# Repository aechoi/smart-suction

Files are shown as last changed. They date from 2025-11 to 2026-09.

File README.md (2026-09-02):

# smart-suction

Single source of truth for the smart suction cup project — a suction cup end
effector that senses contact and alignment from capacitance changes across
eight electrodes.

```
smart-suction/
├── hardware/   KiCad sources for the sense boards and interconnect PCBs
├── firmware/   ESP32 end-effector firmware
├── software/   live capture, analysis, models
└── docs/       diagrams and notes
```

Each part has its own README with setup and usage.

## How the pieces fit

```mermaid
graph LR
    S[AD7746 CDC + 8 electrodes] -->|I2C| E[ESP32 + Ethernet PHY]
    E -->|UDP over PoE| H[Host PC: capcup.udp_receiver]
    H --> A[Analysis notebooks / models]
```

The end effector (`firmware/`) samples eight capacitance channels and streams
40-byte UDP packets to a host PC. `software/` records them and runs the
analysis and position-estimation models.

## How to record data

You will need:

- 1x PoE injector
- 2x ethernet cables
- 1x computer with `software/` installed

```mermaid
graph LR
    A[Outlet] -->|Power| B[PoE Injector]
    B <-->|LAN — ethernet| C[Host PC]
    B <-->|LAN + DC — ethernet| D[End Effector]
```

Then, from `software/`, run `python -m capcup.udp_receiver -f my_capture`.
Two windows open: a rolling time-domain plot and a radial plot.

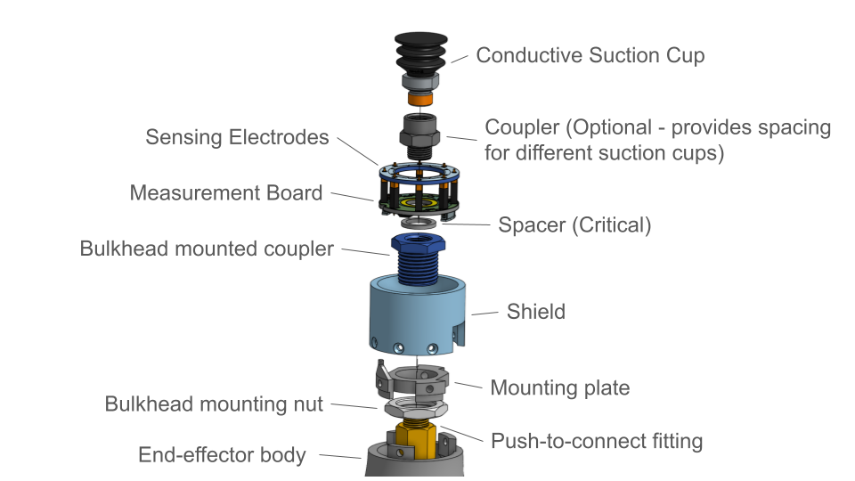
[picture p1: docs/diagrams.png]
Hardware setup


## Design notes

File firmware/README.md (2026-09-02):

# End-effector firmware

Firmware for the smart suction cup end effector. Reads eight capacitance
channels from an AD7746 CDC (multiplexed through GPIO switches) and streams
them over UDP/Ethernet to a host PC running `software/` `udp_receiver.py`.

## Target

- **MCU:** ESP32 with a LAN8720 Ethernet PHY (e.g. WT32-ETH01 / Olimex
  ESP32-POE). RMII pins are set in `ethernet.ino`
  (`MDC=23`, `MDIO=18`, `CLK=GPIO0`, `POWER=-1`).
- **Sensor:** AD7746 capacitance-to-digital converter on I2C
  (`SDA=32`, `SCL=33`, `RDY=36`, address `0x48`), with 8 channels selected
  one at a time via the switch pins in `sensing.ino`.

## Toolchain

Arduino IDE (or `arduino-cli`) with the **esp32 by Espressif** board package.
No external libraries — `ETH.h`, `WiFiUDP.h`, and `Wire.h` all ship with the
core.

The three files form one sketch (`firmware.ino` holds `setup()` / `loop()`;
`ethernet.ino` and `sensing.ino` are additional tabs). Arduino requires the
main file to match the folder name, hence `firmware.ino` in `firmware/`.

## Network configuration

Edit before flashing:

| Where | Constant | Meaning |
|---|---|---|
| `firmware.ino` | `destIP`, `destPort` | host PC address + UDP port (default `12345`) |
| `ethernet.ino` | `localIP`, `gateway`, `subnet` | static IP of the end effector |

## Wire format

One 40-byte UDP packet per sample loop:

| Bytes | Type | Contents |
|---|---|---|
| 0–7 | `uint64` LE | `millis()` timestamp |
| 8–39  | 8 × `int32` LE | raw AD7746 counts, channels 0–7 |

Convert counts to femtofarads with `count2ff()` in `sensing.ino`
(`(counts - 208400) * (4.096 * 1000 * 2) / 2^24`).

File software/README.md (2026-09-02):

# capcup — smart suction cup software

Recording and analyzing capacitance data from the smart suction cup end
effector. See the [repository README](../README.md) for the full project
(hardware, firmware, software).

## Layout

```
software/
├── src/capcup/          installable package
│   ├── udp_receiver.py   live capture + plotting from the end effector
│   ├── simulator/        capacitance-probe forward simulation
│   └── jubilee/          ground-truth collection on the Jubilee platform
├── notebooks/           analysis notebooks (outputs stripped on commit)
│   └── experiments/      one notebook per historical experiment
├── models/             trained weights (gitignored; regenerate from notebooks)
├── figs/               generated figures (gitignored)
└── tests/
```

## Setup

Run from this `software/` directory.

```bash
python -m venv .venv
.venv\Scripts\activate          # Windows
# source .venv/bin/activate     # Linux / macOS
python -m pip install --upgrade pip
pip install -e ".[dev,notebooks]"
```

`pip install -e .` alone installs just the runtime package. The Jubilee
scripts additionally need `jubilee_controller` (see `pyproject.toml`).

## Recording data

See [the repo README](../README.md#how-to-record-data) for the wiring. Then:

```bash
python -m capcup.udp_receiver -f my_capture.csv
```

Two windows open: a rolling time-domain plot and a radial plot. Captures
are written under `data/` (gitignored).

## Before pushing

```bash
pytest
ruff check .
```

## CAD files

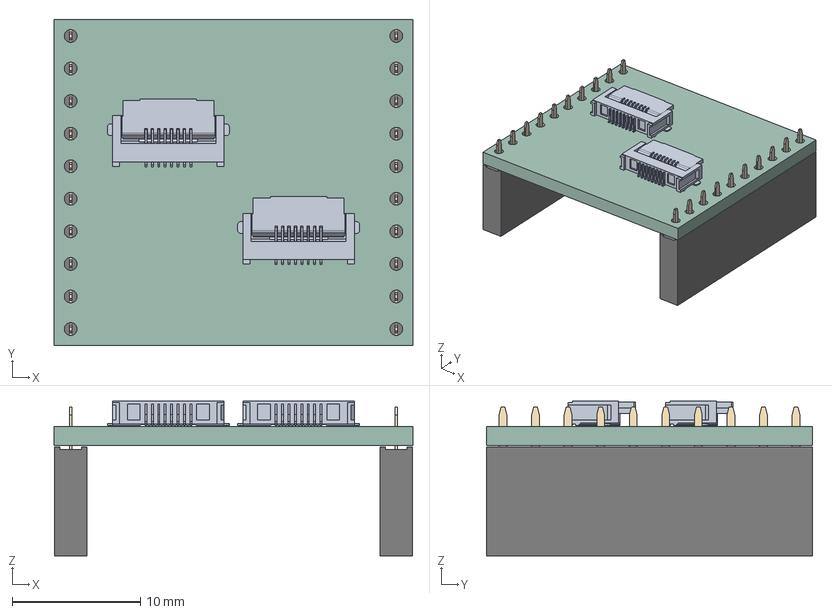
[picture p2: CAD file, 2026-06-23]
hardware/esp_pin_to_ribbon/esp_pin_to_ribbon.step
28.0 x 25.4 x 12.1 mm
PinSocket_1x10_P2.54mm_Vertical x 2
esp_pin_to_ribbon_PCB

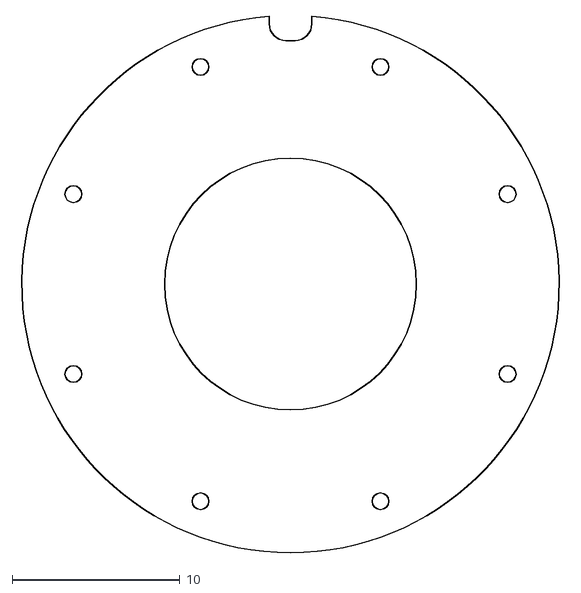
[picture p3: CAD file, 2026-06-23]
hardware/measure_board_v3/measure board 32mm.dxf
32.7 x 31.9

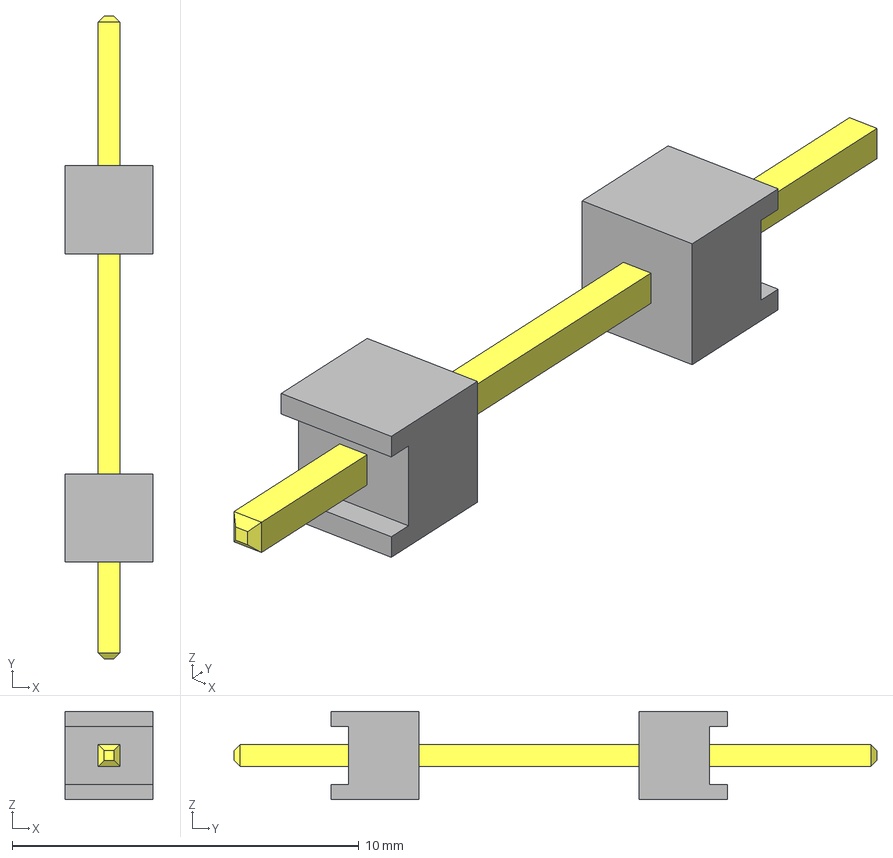
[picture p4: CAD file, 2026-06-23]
hardware/sense_board_20mm_v2/SAMTEC_DW0109TS450/DW-01-09-T-S-450.stp
2.54 x 18.5 x 2.54 mm
ZW-01-09-G-S-450-110bbody
ZW-01-09-G-S-450-110_pins
ZW-01-09-G-S-450-110_top_body

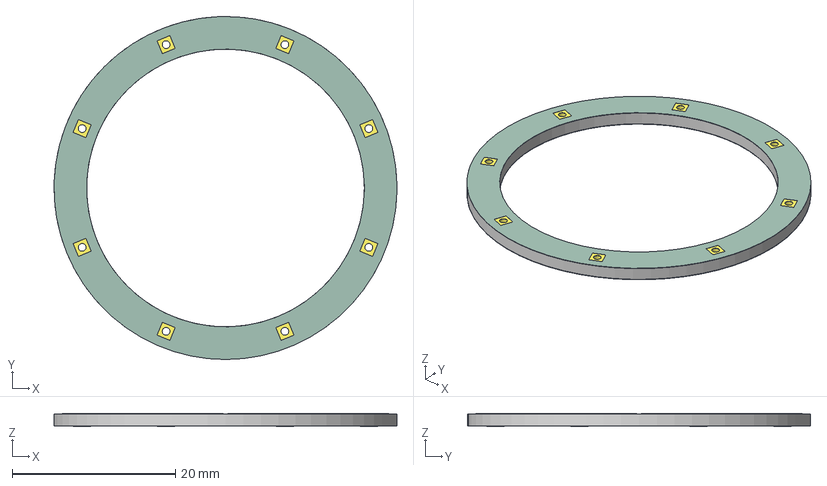
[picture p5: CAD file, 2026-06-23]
hardware/sense_board_20mm_v2/sense_board_20mm_v2.step
42.0 x 42.0 x 1.61 mm
mounted_cap_sense_v1_copper
mounted_cap_sense_v1_pad
mounted_cap_sense_v1_soldermask
mounted_cap_sense_v1_PCB

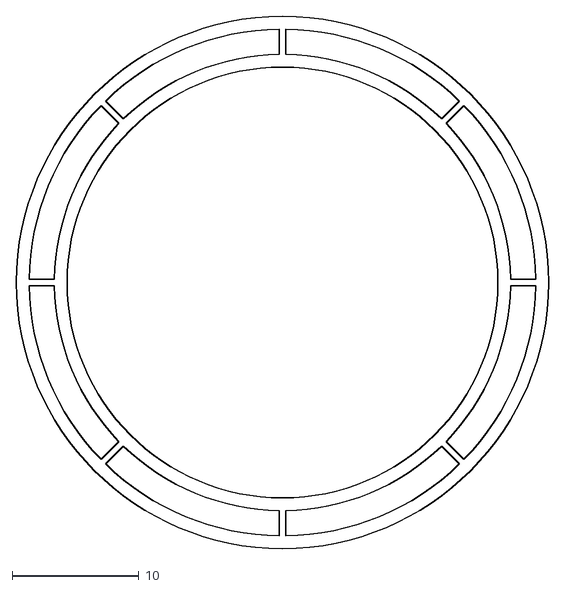
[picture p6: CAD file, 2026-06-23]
hardware/sense_board_25mm_v2/electrode_plate_v1.dxf
42.0 x 42.0

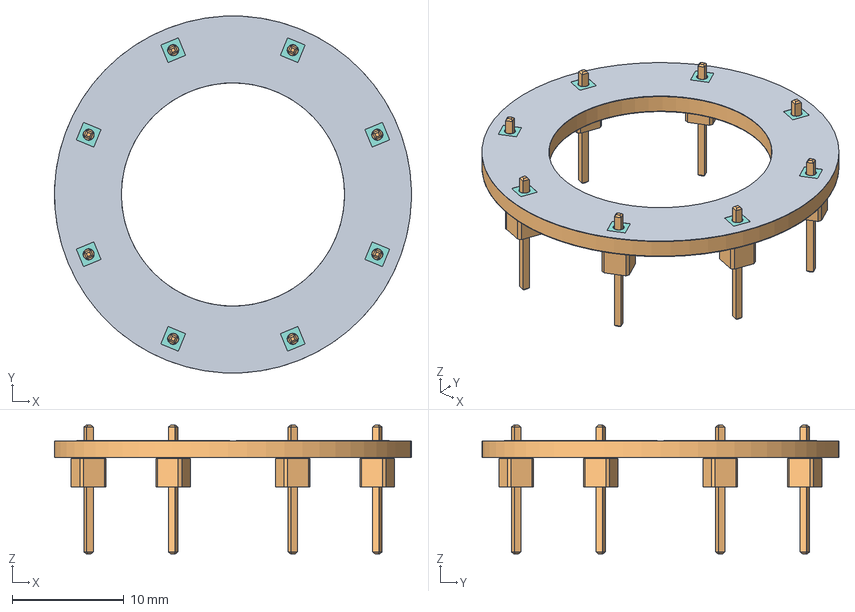
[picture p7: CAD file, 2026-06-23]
hardware/sense_board_30mm_v2/sense_board_30mm_v2.step
32.0 x 32.0 x 11.5 mm
PinHeader_1x01_P2.54mm_Vertical x 8
mounted_cap_sense_v2_25mm_copper
mounted_cap_sense_v2_25mm_pad
mounted_cap_sense_v2_25mm_soldermask
mounted_cap_sense_v2_25mm_PCB

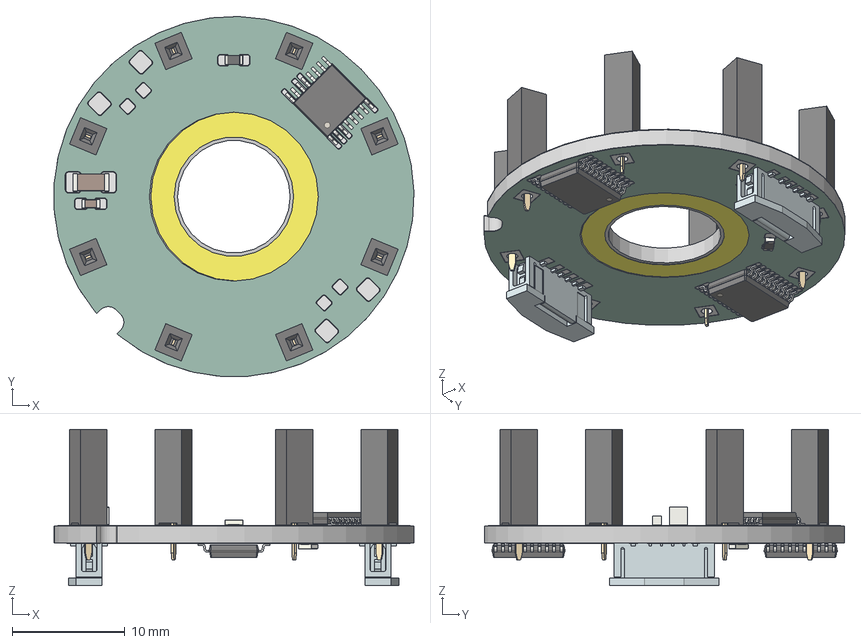
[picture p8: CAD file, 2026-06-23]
hardware/measure_board_v3/measure_board_v3.step
32.0 x 32.0 x 13.9 mm
R_0603_1608Metric x 2
PinSocket_1x01_P2.54mm_Vertical x 8
TSSOP-16_4.4x5mm_P0.65mm
C_1206_3216Metric
C_0603_1608Metric
0525590870_8pin x 2
TSSOP-20_4.4x6.5mm_P0.65mm x 2
muxed_sense_v3_copper
muxed_sense_v3_pad
muxed_sense_v3_soldermask x 2
muxed_sense_v3_PCB

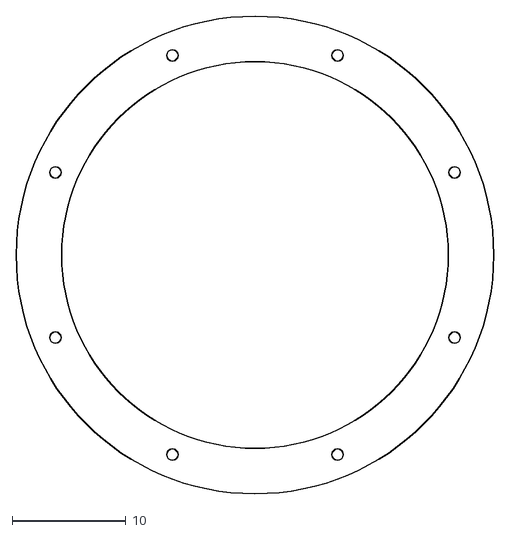
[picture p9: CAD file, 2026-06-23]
hardware/sense_board_30mm_v2/electrode_plate_holes_v1.dxf
42.0 x 42.0

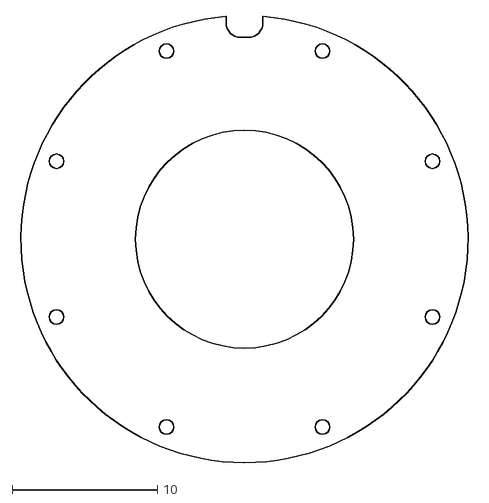
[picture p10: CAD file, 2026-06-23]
hardware/measure_board_v3/measure board 30.762mm.dxf
31.4 x 30.7

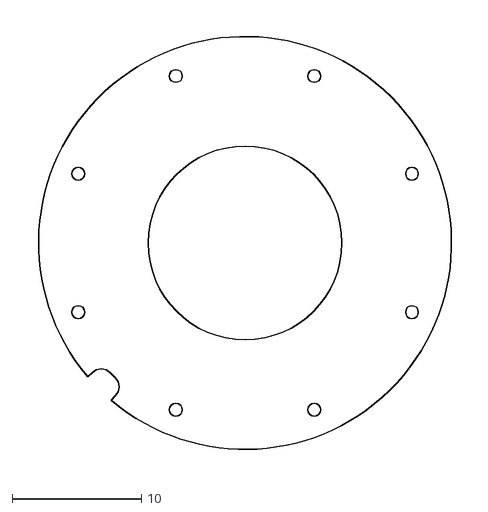
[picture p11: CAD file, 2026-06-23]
hardware/measure_board_v3/measure board 32mm flipped.dxf
35.3 x 35.3

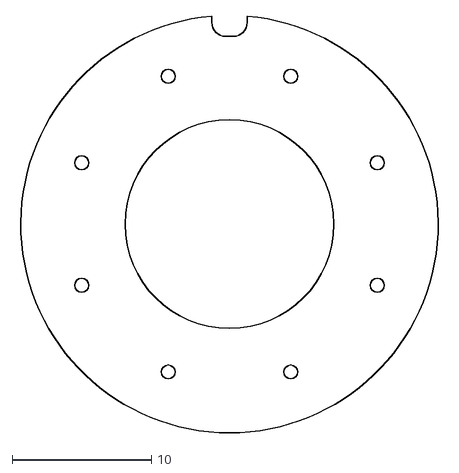
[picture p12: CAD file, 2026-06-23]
hardware/measure_board_v3/measure board 30mm.dxf
30.7 x 29.9

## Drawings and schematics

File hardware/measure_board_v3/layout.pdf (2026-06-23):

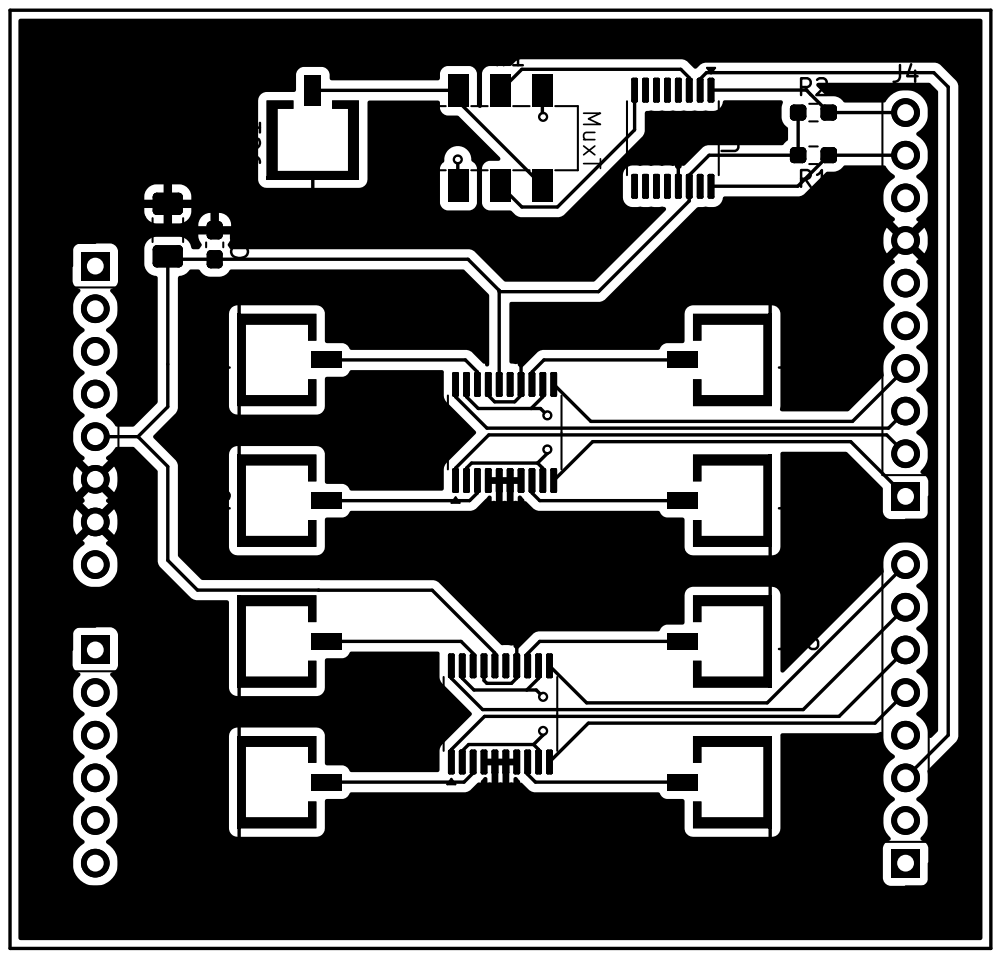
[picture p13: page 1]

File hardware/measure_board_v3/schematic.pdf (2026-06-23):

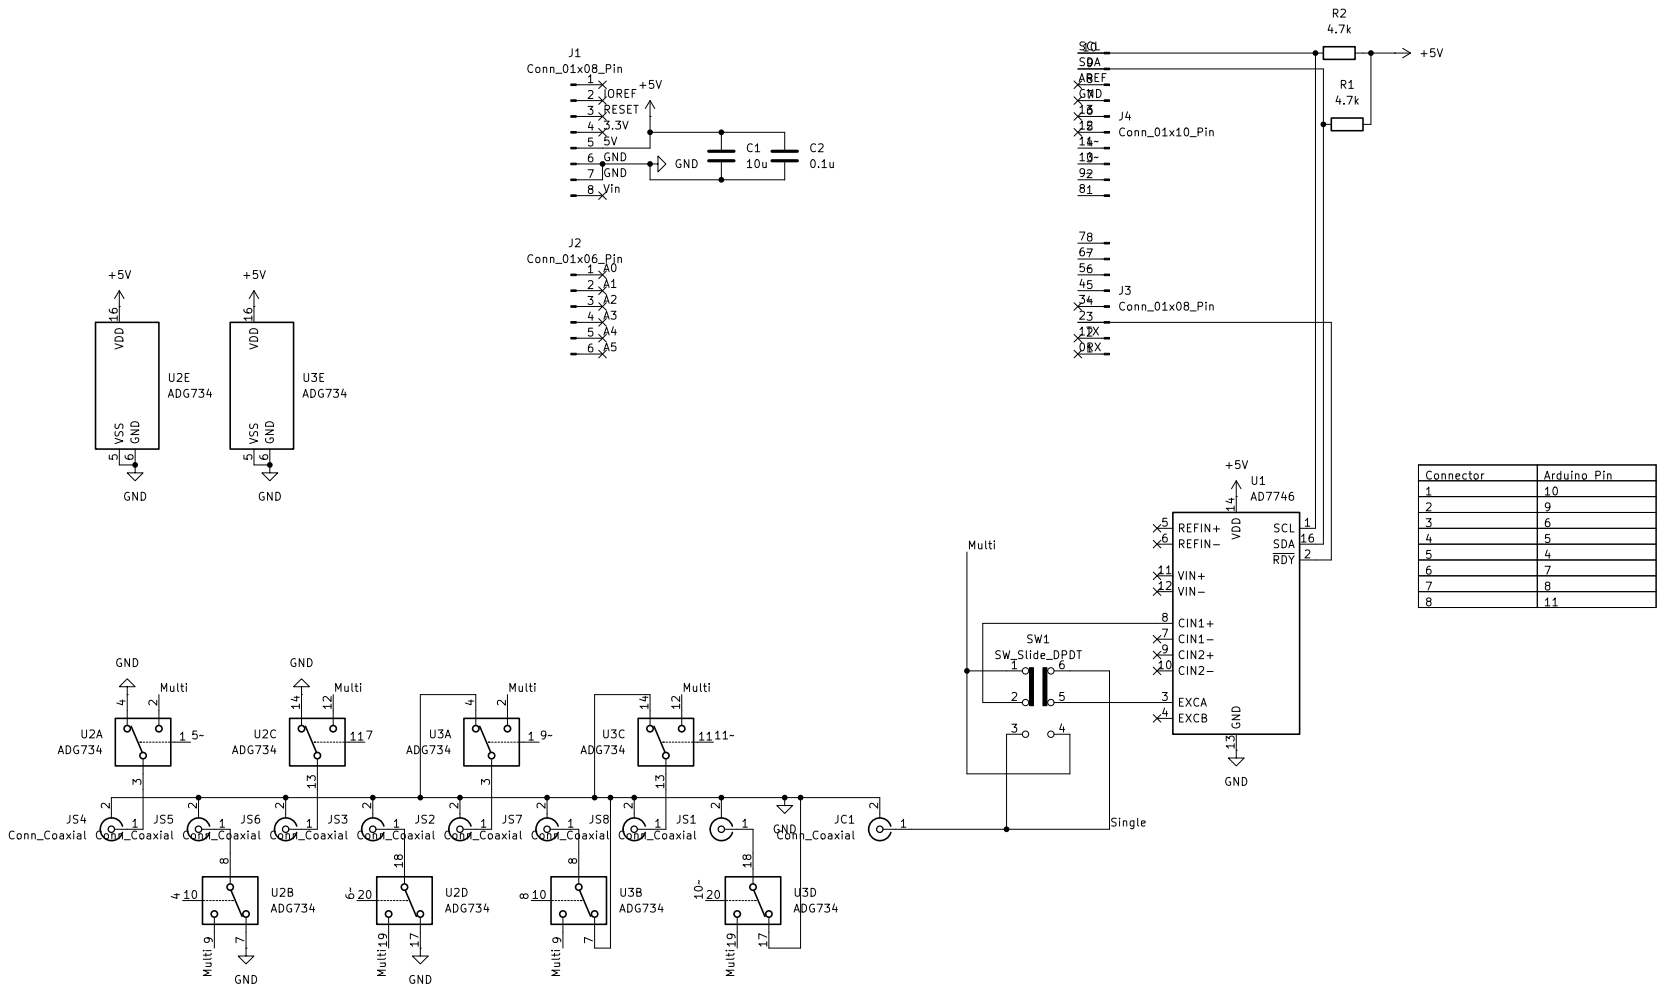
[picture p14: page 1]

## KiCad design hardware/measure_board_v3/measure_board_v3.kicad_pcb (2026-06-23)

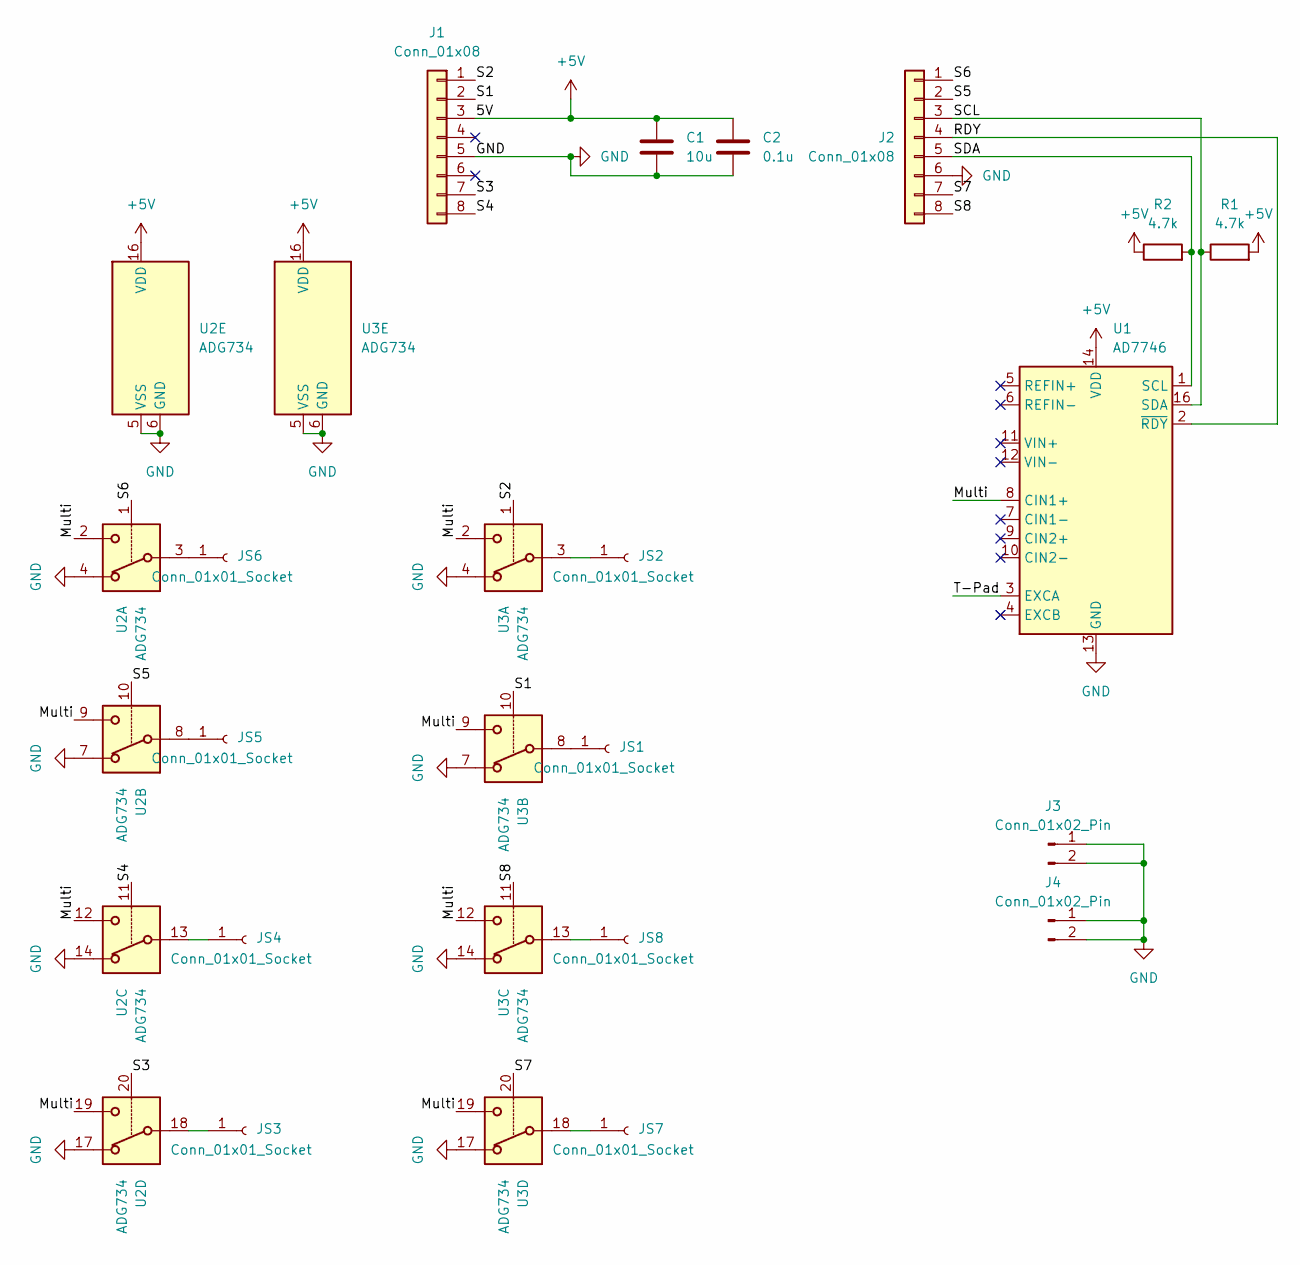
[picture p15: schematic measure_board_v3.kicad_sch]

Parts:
C1: 10u; C_1206_3216Metric_Pad1.33x1.80mm_HandSolder
C2: 0.1u; C_0603_1608Metric_Pad1.08x0.95mm_HandSolder
J1, J2: Conn_01x08; CON_525590870_MOL_8pv
J3, J4: Conn_01x02_Pin; CON_spring_00-9155-00X-85X-00X_KYOCERA
JS1, JS2, JS3, JS4, JS5, JS6, JS7, JS8: Conn_01x01_Socket; PinSocket_1x01_P2.54mm_Vertical
R1, R2: 4.7k; R_0603_1608Metric_Pad0.98x0.95mm_HandSolder
U1: AD7746; TSSOP-16_4.4x5mm_P0.65mm
U2, U3: ADG734; TSSOP-20_4.4x6.5mm_P0.65mm

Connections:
+5V: C1.1, C2.1, J1.3, R1.2, R2.1, U1.14 (VDD), U2.16 (VDD), U3.16 (VDD)
/Multi: U1.8 (CIN1+), U2.2, U2.9, U2.12, U2.19, U3.2, U3.9, U3.12, U3.19
/RDY: J2.4, U1.2 (~RDY)
/S1: J1.2, U3.10
/S2: J1.1, U3.1
/S3: J1.7, U2.20
/S4: J1.8, U2.11
/S5: J2.2, U2.10
/S6: J2.1, U2.1
/S7: J2.7, U3.20
/S8: J2.8, U3.11
/SCL: J2.3, R1.1, U1.16 (SDA)
/SDA: J2.5, R2.2, U1.1 (SCL)
/T-Pad: U1.3 (EXCA)
GND: C1.2, C2.2, J1.5, J2.6, J3.1, J3.2, J4.1, J4.2, U1.13 (GND), U2.4, U2.5 (VSS), U2.6 (GND), U2.7, U2.14, U2.17, U3.4, U3.5 (VSS), U3.6 (GND), U3.7, U3.14, U3.17
unnamed: JS1.1, U3.8
unnamed: JS2.1, U3.3
unnamed: JS3.1, U2.18
unnamed: JS4.1, U2.13
unnamed: JS5.1, U2.8
unnamed: JS6.1, U2.3
unnamed: JS7.1, U3.18
unnamed: JS8.1, U3.13

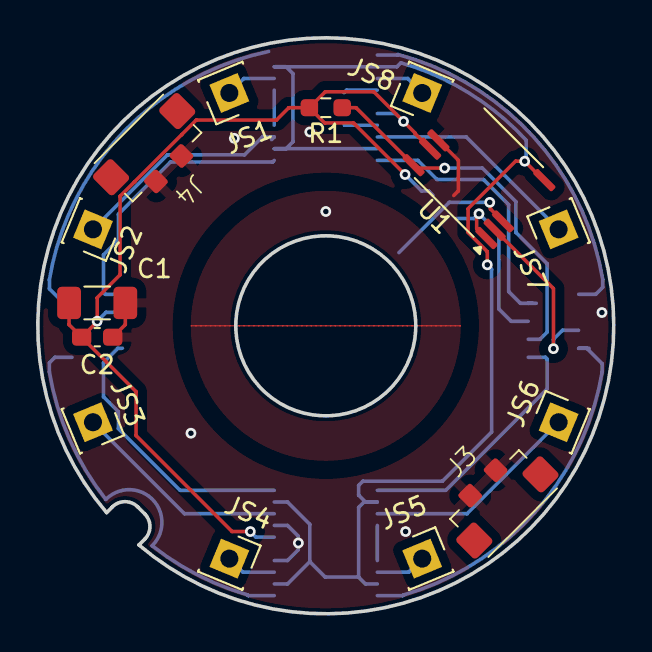
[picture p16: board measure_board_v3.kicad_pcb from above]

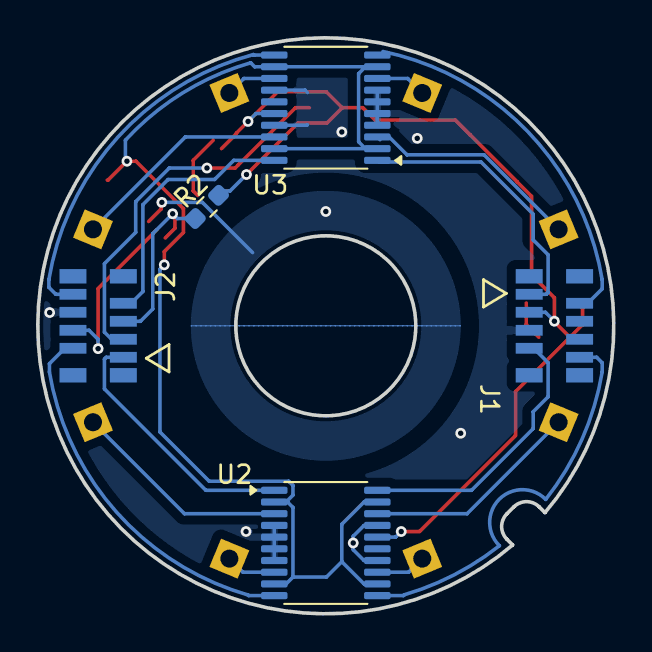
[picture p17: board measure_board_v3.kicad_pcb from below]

Board: 2 copper layers, 32.0 x 32.0 mm, 19 parts (5 on the bottom side), 22 nets.

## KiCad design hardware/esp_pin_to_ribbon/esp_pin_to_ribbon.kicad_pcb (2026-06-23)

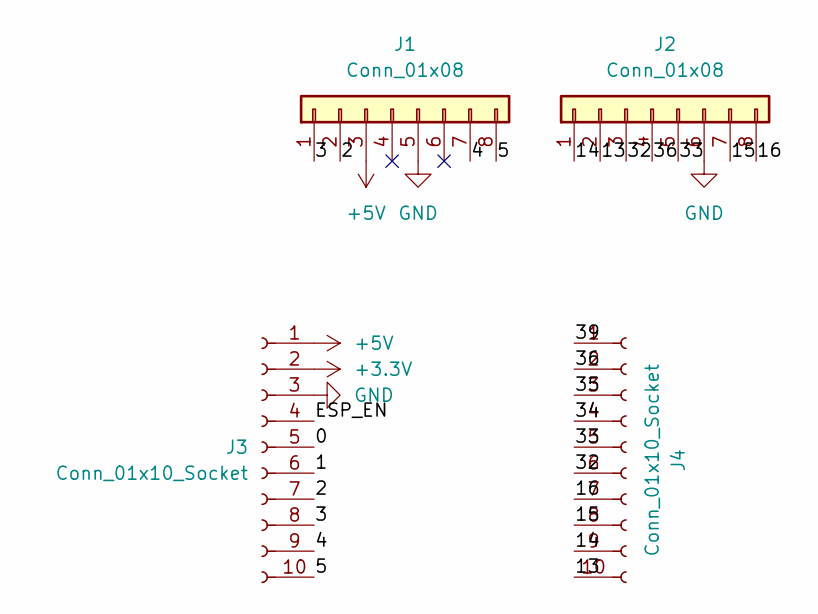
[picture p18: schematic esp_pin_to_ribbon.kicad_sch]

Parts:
J1, J2: Conn_01x08; CON_5051100892_MOL_8ph
J3, J4: Conn_01x10_Socket; PinSocket_1x10_P2.54mm_Vertical

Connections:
+3.3V: J3.2
+5V: J1.3, J3.1
/0: J3.5
/1: J3.6
/2: J1.2, J3.7
/3: J1.1, J3.8
/4: J1.7, J3.9
/5: J1.8, J3.10
/13: J2.2, J4.10
/14: J2.1, J4.9
/15: J2.7, J4.8
/16: J2.8, J4.7
/32: J2.3, J4.6
/33: J2.5, J4.5
/34: J4.4
/35: J4.3
/36: J2.4, J4.2
/39: J4.1
/ESP_EN: J3.4
GND: J1.5, J2.6, J3.3

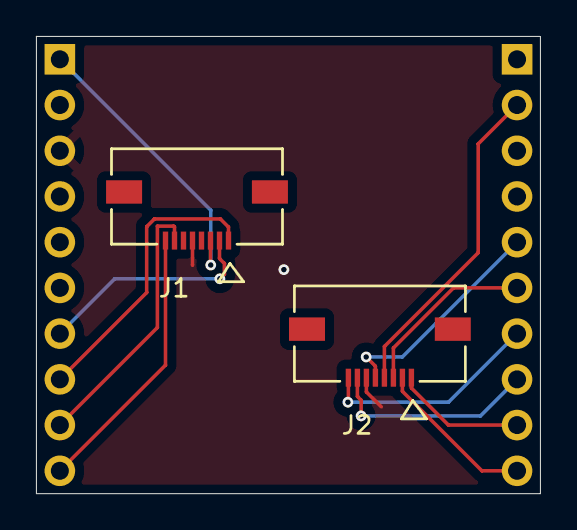
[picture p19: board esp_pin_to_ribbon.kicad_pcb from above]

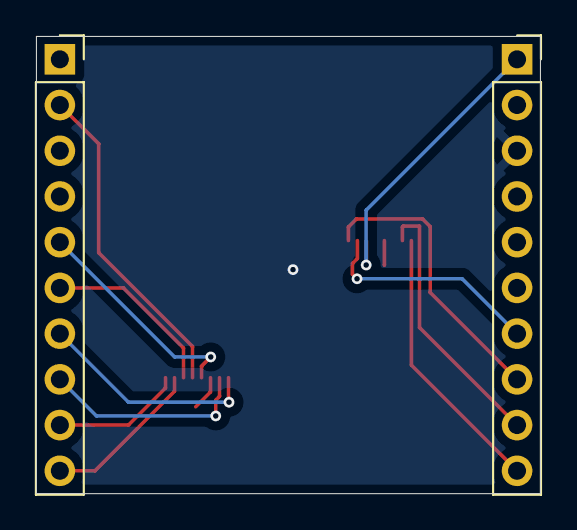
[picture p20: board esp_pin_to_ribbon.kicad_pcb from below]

Board: 2 copper layers, 28.0 x 25.4 mm, 4 parts (2 on the bottom side), 13 nets.

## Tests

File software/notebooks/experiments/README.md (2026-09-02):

# Experiment records

One notebook per experiment run, kept as a frozen record — **rendered output
is committed on purpose** (these are excluded from the `nbstripout`
pre-commit hook).

## Adding a new experiment

For anything you want to refer back to later, make a folder:

```
experiments/2026-09-15_electrode-spacing/
├── README.md      what was tested, hardware/rig config, raw-data location
├── analysis.ipynb the notebook
└── report.html    executed notebook, exported  (the permanent record)
```

Export the rendered report with:

```bash
python -m nbconvert --to html --output report.html analysis.ipynb
```

Reusable analysis code (loading a capture, SNR, standard plots) belongs in
`capcup`, not copied between notebooks. Raw captures stay out of git — note
their location in the experiment README.

## Existing notebooks

The loose `*.ipynb` here predate this convention; they are kept as-is.

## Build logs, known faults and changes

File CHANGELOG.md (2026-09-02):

# Changelog

## Repo cleanup — 2026-09-02

Reorganized from an ad-hoc layout into a hardware/firmware/software monorepo.

### Structure
- `software/` now holds the Python side (package, notebooks, tests); was the
  repo root.
- `firmware/` added — the ESP32 end-effector Arduino sketch.
- `hardware/` unchanged; `assets/` → `docs/`.
- Package `capcup`: `jubliee_scripting/` renamed to `jubilee/`, notebooks and
  `figs/` moved out of the importable package.

### Removed
- 95 KiCad auto-backup zips, stale gerber/vendor zips, `fp-info-cache`,
  `*.kicad_prl`, autosaves — all recoverable from history.
- Trained weights (`*.pt`) and generated `figs/` are no longer tracked.
- Serial capture and eval-board data-processing code — see tag
  `archive/serial-and-eval-pipeline`.

### Tooling
- `pyproject.toml`: correct package path, real dependencies, `[dev]` /
  `[notebooks]` extras, ruff + pytest config, `capcup-record` entry point.
- Added `.pre-commit-config.yaml` (ruff, nbstripout, hygiene) and a
  GitHub Actions CI workflow.
- `.gitattributes` for line-ending normalization.
- Notebook outputs stripped from the active notebooks; experiment records
  under `software/notebooks/experiments/` keep theirs.

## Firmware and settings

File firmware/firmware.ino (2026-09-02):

#include <WiFiUdp.h>

WiFiUDP udp;
// IPAddress destIP(192,168,1,100);  // your laptop
IPAddress destIP(192,168,10,102);
const uint16_t destPort = 12345;
uint8_t packet[40];
long cap_vals[8] = {0};

void setup() {
  delay(500);
  Serial.begin(115200);

  Serial.println("");
  Serial.println("Attempting Ethernet Setup...");
  ethernet_init();

  Serial.println("Attempting Sensing Setup...");
  sensing_setup();
}

void loop() {
  take_measurements(cap_vals);
  uint64_t t = millis();
  memcpy(packet, &t, sizeof(t));
  // Serial.print(t);
  // Serial.print(" ");
  // Serial.print(sizeof(t));
  // Serial.print(" ");

  // for (long cap : cap_vals) {
  //   Serial.print(cap);
  //   Serial.print(" ");
  // }
  // Serial.println();



  for (int i = 0; i<8; i++) {
    memcpy(packet + 8 + i * sizeof(long), &cap_vals[i], sizeof(long));
  }

  udp.beginPacket(destIP, destPort);
  // udp.print("hello from esp32\n");
  udp.write(packet, sizeof(packet));
  udp.endPacket();

  // delay(500);
}

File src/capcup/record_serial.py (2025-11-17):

import argparse
from collections import deque
import serial
import time

import matplotlib.pyplot as plt
from matplotlib.patches import Arc
from matplotlib.widgets import Button
import numpy as np
import torch
from torch import nn

# Parse args
parser = argparse.ArgumentParser()
parser.add_argument(
    "-f", "--file", type=str, default="test", help="File name to save data to"
)
parser.add_argument(
    "-t",
    "--time_stop",
    type=int,
    default=0,
    help="Time from last actuation to stop recording",
)
parser.add_argument(
    "--no-viz",
    action="store_false",
    dest="viz",
    help="Turn off the visualizer",
)
parser.add_argument(
    "--no-viz2",
    action="store_false",
    dest="viz2",
    help="Turn off the second vizualizer",
)
args = parser.parse_args()

file = args.file + ".csv"
time_stop = args.time_stop
viz = args.viz
viz2 = args.viz2

print("Saving to", file)

# Serial Setup
data_points = 8 + 1  # 8 channels + 1 actuation flag
ser = serial.Serial("/dev/ttyACM0", 115200, timeout=1)
print("Attempting to read...")
# Get first entry to initialize plot
while True:
    try:
        line = ser.readline().decode("utf-8").strip()
        values = [int(entry) for entry in line.split(" ")]
        if len(values) == data_points:
            break
    except Exception as e:
        pass
print("Stream read, starting")

# Plotting Setup ##########

window = 100
data = deque([values] * window, maxlen=window)
offsets = np.array(values) - 10000 * np.arange(data_points)
if viz:
    plt.ion()
    fig, ax = plt.subplots()
    channels = ax.plot(np.array(data) - offsets)
    ax.legend(
        [f"C{i+1}" for i in range(data_points - 1)] + ["Actuation"], loc="upper left"
    )
    ax.set_xlabel("Samples")
    ax.set_ylabel("Normalized and Offset ADC Counts")
    ax.set_title("Live Viewer")


zeros = None
scale = 100000
if viz2:
    plt.ion()
    fig2, ax2 = plt.subplots()
    ax2.axis("off")
    arcs = []

    text_r = 0.75
    text_thetas = np.linspace(
        np.pi / 8 + np.pi / 2, 2 * np.pi - np.pi / 8 + np.pi / 2, 8
    )
    text_x = text_r * np.cos(text_thetas)
    text_y = text_r * np.sin(text_thetas)
    for idx in range(8):
        arcs.append(
            Arc(
                (0, 0),
                1,
                1,
                angle=0,
                theta1=idx * 45 + 90 + 2,
                theta2=idx * 45 + 45 + 90 - 2,
                lw=15,
            )
        )
        ax2.text(text_x[-1 - idx], text_y[-1 - idx], f"{idx + 1}")
        ax2.add_patch(arcs[-1])

    ax2.set_xlim(-1, 1)
    ax2.set_ylim(-1, 1)
    ax2.set_aspect("equal")
    cmap = plt.cm.seismic
    norm = plt.Normalize(vmin=-1, vmax=1)

    # Define the callback function
    def on_button_click(event):
        global zeros
        zeros = None

    # Create a button axis (position: [left, bottom, width, height])
    button_ax = plt.axes([0.4, 0.05, 0.2, 0.075])
    button = Button(button_ax, "Reset Zero")

    # Connect the callback
    button.on_clicked(on_button_click)

############################


### Inference Setup
class LSTMCorrection(nn.Module):
    def __init__(
        self,
        input_dim=8,
        hidden_dim=64,
        num_layers=2,
        output_dim=2,
        bidirectional=False,
        dropout=0,
    ):
        super().__init__()
        self.hidden_dim = hidden_dim
        self.num_layers = num_layers
        self.bidirectional = bidirectional
        self.num_directions = 2 if bidirectional else 1

        self.lstm = nn.LSTM(
            input_size=input_dim,
            hidden_size=hidden_dim,
            num_layers=num_layers,
            batch_first=True,
            dropout=dropout if num_layers > 1 else 0,
            bidirectional=bidirectional,
        )
        self.fc = nn.Linear(hidden_dim * self.num_directions, output_dim)

    def forward(self, x, hidden=None):
        out, hidden = self.lstm(x, hidden)
        out = self.fc(out)
        return out, hidden


device = (
    torch.accelerator.current_accelerator().type
    if torch.accelerator.is_available()
    else "cpu"
)
print(f"Using {device} device")
model = LSTMCorrection(num_layers=4)
model.load_state_dict(torch.load("lstm_model.pt", map_location=device))
model.eval()
num_layers = 4
hidden_dim = 64
h = torch.zeros(num_layers, 1, hidden_dim)
c = torch.zeros(num_layers, 1, hidden_dim)
hidden = (h, c)
x = torch.tensor(values[:-1], dtype=torch.float32).unsqueeze(0).unsqueeze(0)
pred, hidden = model(x, hidden)
#####


class BufferMonitor:
    def __init__(self, ser, max_buffer=4096):
        self.ser = ser
        self.max_buffer = max_buffer
        self.overflow_count = 0

    def safe_read(self, size):
        """Read with buffer overflow protection"""
        waiting = self.ser.in_waiting

        if waiting > self.max_buffer:
            print(f"!!!  Buffer overflow: {waiting} bytes")
            # Clear excess data
            excess = waiting - self.max_buffer
            discarded = self.ser.read(excess)
            self.overflow_count += 1
            print(f"Discarded {len(discarded)} bytes")

        return self.ser.read(min(size, waiting))

    def get_stats(self):
        return {
            "waiting": self.ser.in_waiting,
            "buffer_usage": f"{self.ser.in_waiting}/{self.max_buffer}",
            "overflows": self.overflow_count,
        }


class BufferOverflowError(IOError):
    pass
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

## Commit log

2025-02-22 initial commit with project set-up boiler plate
2025-02-23 add eval_data_formatter.py which formats downloaded eval board test data into an EvalBoardData object
2025-02-26 add demo notebook showing analysis of initial capacitance data
2025-09-08 add images for silver and printed tests
2025-10-13 add ground truth generation files
2025-10-14 update record_serial to be more robust to buffer issues leading to dropped frames. Also increase baud
    [record_serial.py]
2026-06-23 add board files
    [DW-01-09-T-S-450.stp, electrode_plate_holes_v1.dxf, electrode_plate_v1.dxf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]
2026-09-02 Phase 1: purge tool backups, caches, and sync-duplicate files
    - Remove 95 KiCad auto-backup zips and stale gerber/vendor zips (recoverable
    from history; fabrication outputs will be regenerated into fabrication/)
    - Untrack KiCad local state and caches: fp-info-cache, *.kicad_prl,
    _autosave-*, *-bak, #auto_saved_files#
    - Untrack trained model weights (best_model.pt, lstm_model.pt) - regenerate
    from notebooks
    - Delete Nextcloud-sync duplicate leftovers from the c2f5da8 reorg:
    loose *.py at src/capcup/ root, src/capcup/notebooks/, root viz_notebook.ipynb,
    src/capcup/test.csv
    - Rewrite .gitignore with per-domain sections (Python, KiCad, firmware)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
2026-09-02 Phase 2: archive obsolete serial + eval-board code
    Removed (recoverable from tag archive/serial-and-eval-pipeline):
    - src/capcup/data_collection/ - serial capture from Arduino/ESP32,
    superseded by the UDP path (udp_receiver.py)
    - src/capcup/data_processing/ - parsers for AD7746/ScioSense eval-board
    dumps and the old serial stream format; none used with the current
    UDP pipeline
    - tests/ - the two tests covered only the removed modules (and were
    already broken: wrong import path, data never committed)
    [eval_data_formatter.py, record_serial.py]
2026-09-02 Phase 3: restructure into a hardware/firmware/software monorepo
    Layout:
    - software/ Python package (was repo root)
    - src/capcup/ udp_receiver + simulator/ + jubilee/
    - notebooks/ moved out of the package; experiments/ holds the
    per-experiment analysis notebooks
    - models/, figs/ generated artifacts, now gitignored
    - tests/test_smoke.py import smoke test (old tests were for removed code)
    - firmware/ end-effector Arduino sketch (imported from the research tree)
    - docs/ diagrams (was assets/)
    - hardware/ unchanged
    Package fixes:
    - pyproject.toml: correct package path (was src/smart-suction), real
    dependency list,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
    [firmware.ino]
2026-09-02 Phase 4: docs, lint, and CI tooling
    - README.md rewritten as the project (hw/fw/sw) overview, with the
    cross-machine git workflow and an archived-code table
    - software/README.md and firmware/README.md (added in Phase 3) cover
    per-domain setup
    - software/notebooks/experiments/README.md documents the experiment-record
    convention
    - CHANGELOG.md records this cleanup
    - .pre-commit-config.yaml: ruff, nbstripout (experiments/ excluded),
    whitespace/large-file hygiene
    - .github/workflows/ci.yml: ruff + pytest on software/
    - pyproject.toml: pin ruff rule set, exclude notebooks, per-file F841 ignores
    - ruff --fix + small manual fixes across capcup (import order, py3.10
    syntax, ambiguous names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
2026-09-02 Tighten pre-commit hook scope and apply first pass
    - trailing-whitespace / end-of-file-fixer: exclude hardware/ and
    binary-ish formats (.step/.stp/.dxf/.sch) so KiCad/CAD files are never
    rewritten; ruff scoped to software/**/*.py
    - apply the resulting whitespace + nbstripout fixes
    [sensing.ino]

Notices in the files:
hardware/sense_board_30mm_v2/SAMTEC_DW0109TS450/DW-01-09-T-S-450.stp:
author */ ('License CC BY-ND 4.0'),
